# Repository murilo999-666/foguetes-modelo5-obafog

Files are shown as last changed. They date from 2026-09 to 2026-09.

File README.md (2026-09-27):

# Dois foguetes com o motor sólido da OBAFOG

**Página do projeto: https://murilo999-666.github.io/foguetes-modelo5-obafog/**
(gráficos, vistas do OpenRocket, modelos 3D que giram, estimativas e o plano até a Jornada)

Um foguete de alcance para o Modelo 5 da OBAFOG (100ª Jornada de Foguetes, Turma 15,
dezembro de 2026) e um foguete livre com computador de voo e paraquedas. Os dois usam o motor
sólido oficial da OBAFOG e são impressos em 3D.

| | Foguete 1 — OBAFOG Modelo 5 | Foguete 2 — livre |
|---|---|---|
| Objetivo | maior alcance horizontal | voo vertical com eletrônica e paraquedas |
| Simulado com o motor nominal (7 N·s) | 384 m de alcance, a 44° | 114 m de apogeu, descida a 4,5 m/s |
| Arquivo principal | `foguete1_obafog/F1_construtivel_v1.ork` | `foguete2_livre/F2_29mm_v1.ork` |
| Resumo | [foguete1_obafog/LEIA-ME.md](foguete1_obafog/LEIA-ME.md) | [foguete2_livre/LEIA-ME.md](foguete2_livre/LEIA-ME.md) |

Os números vêm de simulação no OpenRocket 24.12. A OBA não publica o impulso do motor: a faixa
de projeto vai de 5 a 11,5 N·s, e o teste estático (bancada em `motor/teste_estatico/`) é o
próximo passo para trocar a faixa por um número medido.

## Onde está cada coisa

- [LEIA-ME.md](LEIA-ME.md): índice do projeto e como abrir os arquivos
- [regulamento/CONFORMIDADE.md](regulamento/CONFORMIDADE.md): o regulamento regra por regra, com a página citada
- [pesquisa/PESQUISA.md](pesquisa/PESQUISA.md): dossiê de pesquisa com as fontes
- [motor/](motor/): modelo do motor, curvas `.eng` e bancada de teste estático
- [foguete1_obafog/](foguete1_obafog/) e [foguete2_livre/](foguete2_livre/): `.ork`, STL, moldes, montagem, eletrônica e firmware
- [scripts/](scripts/): o código que gerou os números (OpenRocket via Python, CAD, otimização)
- [REVISAO.md](REVISAO.md): revisão crítica do projeto
- [docs/](docs/): o código da página

Os PDFs de terceiros usados na pesquisa não foram republicados aqui; os links para eles estão
em `pesquisa/PESQUISA.md`.

## Segurança

O motor deve ser feito exatamente como nos vídeos oficiais da OBA, com o professor. Este
repositório não traz a receita do propelente e não recomenda nenhuma alteração no motor.

---

Projeto de Murilo ([@murilo999-666](https://github.com/murilo999-666)). Pesquisa, simulações,
CAD e código desenvolvidos com auxílio do Claude, a IA da Anthropic.

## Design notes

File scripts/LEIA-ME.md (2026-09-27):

# Scripts — como refazer tudo

Dois Pythons:
- **venv do orx** (`C:\Users\muril\openrocket-optimizer\.venv\Scripts\python.exe`): tudo que usa
  o OpenRocket 24.12 (JPype). Rodar sempre com `-u -X utf8`.
- **Python do sistema** (`python`): CAD (`trimesh` + `manifold3d`), moldes em PDF, imagens.

| Script | Python | O que faz |
|---|---|---|
| `m5lib.py` | venv | biblioteca: constrói os foguetes do zero no OpenRocket (F1, F2, garrafa PET da OBA), motor por configuração de voo, simula cenários, aplica massas do CAD |
| `teste_convencoes.py` | venv | confere azimute, direção do vento e margem estática (rodar depois de mexer na m5lib) |
| `teste_determinismo.py` | venv | mostra que a turbulência do OpenRocket ignora a semente |
| `calibrar_com_voos_oba.py` | venv | garrafas PET de 500 mL x impulso — checagem da faixa do motor |
| `avaliacao.py` / `otimizar_f1.py` | venv | nota robusta e otimização do Foguete 1 (`explorar N`, `humano`; modo construtível por variável de ambiente `M5_MODO=construtivel M5_CONJ=S2`) |
| `avaliar_bf_reto.py` | venv | versões com bordo de fuga reto (imprimível sem suporte) dos melhores construtíveis |
| `comparar_f1.py` | venv | teórico x construtível x humano no mesmo conjunto de cenários; salva `F1_teorico_v1.ork` |
| `finalizar_f1.py <params.json> <versao>` | venv | CAD → massas reais → lastro para 1,40 cal → tabela de ângulos → sensibilidade → Monte Carlo → `.ork` + gráficos + resumo |
| `avaliacao_f2.py` / `otimizar_f2.py` | venv | nota e otimização do Foguete 2 |
| `finalizar_f2.py <params.json> <versao>` | venv | CAD → `.ork` → tabelas de lastro (limite de 150 m) e de deriva → gráfico |
| `exportar_trajetorias_f2.py` | venv | trajetórias do F2 para o teste SIL do firmware |
| `verificar_orks.py` | venv | abre cada `.ork` do disco e roda de novo todas as simulações salvas |
| `cad_foguetes.py f1\|f2\|gabaritos\|massas` | sistema | STL paramétricos e `massas_cad.json` |
| `gerar_moldes.py <D_paraquedas>` | sistema | molde do paraquedas e transferidor da haste (PDF A4, 1:1) |
| `render_previews.py` | sistema | imagem de cada foguete montado |
| `render_openrocket.py <pasta>` | venv, com `ORX_JVM_OPTS=-Djava.awt.headless=false` | vistas lateral e traseira desenhadas pelo próprio OpenRocket (CG, CP, massas), em PNG |
| `exportar_dados_site.py <pasta da página>` | venv | números e curvas da página → `assets/dados.js` |
| `gerar_modelos_web.py <pasta>` | sistema | STL leves para o visualizador 3D da página + `modelos.json` (massas do STL de impressão) |

A página do projeto fica em `../docs/` (GitHub Pages). Depois de mudar um foguete, atualize com
`exportar_dados_site.py ../docs`, `gerar_modelos_web.py ../docs/modelos` e
`render_openrocket.py ../docs/img`.

Os motores são gerados por `../motor/gerar_motores.py` (Python do sistema, só numpy). A curva
medida na bancada entra por `../motor/teste_estatico/para_eng.py`.

Mudou uma cota fixa (diâmetro do cap, folga da impressora)? Edite `m5lib.py`/`cad_foguetes.py`,
rode `finalizar_f1.py`/`finalizar_f2.py` com o `params` da versão e depois `verificar_orks.py`.

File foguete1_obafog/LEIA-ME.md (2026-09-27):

# Foguete 1 — OBAFOG Modelo 5 (alcance)

Corpo de 26 mm impresso, ogiva longa com lastro de massa epóxi no bico, lata de aletas com
luva do motor e as duas guias, motor oficial da OBAFOG preso pelo tubo (o cap fica livre).
Feito para a 100ª Jornada de Foguetes, Turma 15, e serve para a etapa escolar da 21ª OBAFOG.

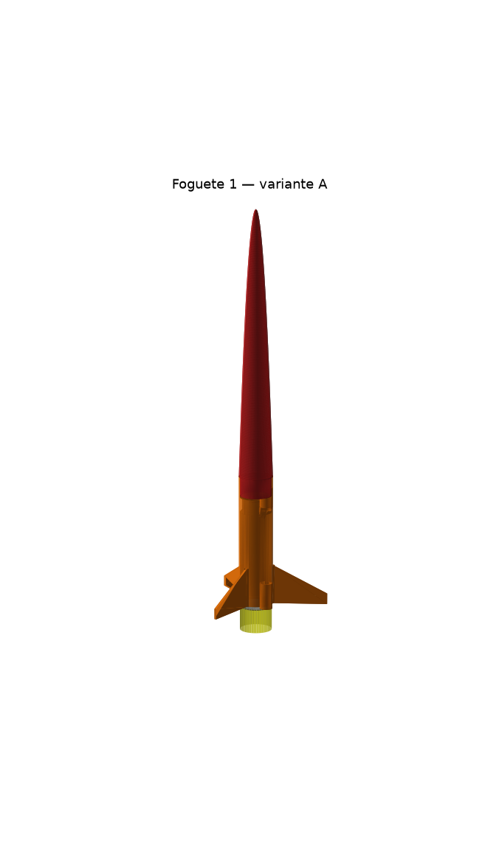
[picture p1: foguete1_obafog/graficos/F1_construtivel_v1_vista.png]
variante A


## Qual imprimir

| | **Variante A** (recomendada) | Variante B (impressora baixa) |
|---|---|---|
| Arquivo | `F1_construtivel_v1.ork` | `F1_construtivel_v1B_ogiva_curta.ork` |
| Peças | **2**: ogiva + lata (as duas guias na lata, alinhadas por construção) | 3: ogiva + tubo + lata (colar com a haste) |
| Ogiva | série de potência (½), 205 mm → **precisa de 220 mm de altura de impressão** | elipsoidal, 150 mm → 165 mm de altura |
| Aletas | 3 x (raiz 30, ponta 8, envergadura 42, bordo de fuga reto), 1,6 mm | 4 x (29, 9, 36), 1,6 mm |
| Lastro de massa epóxi no bico | **12 g** | **9 g** |
| Massa na decolagem (com motor) | **86 g** | 89 g |
| Margem estática com motor / queimado | **1,41 / 2,06 cal** | 1,41 cal |
| Alcance, motor nominal 7 N·s, 44°, sem vento | **384 m** | 363 m |
| 5 / 9 / 11,5 N·s | 248 / 495 / 603 m | 234 / 469 / — |
| Monte Carlo (200 voos com vento, rajada, motor e montagem sorteados) P10 / mediana / P90 | **249 / 386 / 508 m** | 234 / 365 / 484 m |

Massas das peças (do CAD): variante A → ogiva 11,7 g, lata 18,7 g. Tudo em
`F1_construtivel_v1_resumo.json`.

**Expectativa honesta:** o OpenRocket deu mais alcance que o real quando testado nas garrafas
da OBA; conte com algo 10–30% abaixo dos números acima até o primeiro voo de teste.
Garrafas típicas da OBA fazem 100–180 m com o mesmo motor.

## Ângulo da haste (variante A; média dos motores de 5, 7 e 9 N·s)

| Vento na direção do lançamento | Ângulo | Alcance médio |
|---|---|---|
| calmo | **44°** | 376 m |
| 2 m/s de frente | 48° | 363 m |
| 4 m/s de frente | 48° | 350 m |
| 6 m/s de frente | 52° | 337 m |
| 2 m/s de cauda | 44° | 388 m |
| 4 m/s de cauda | 40° | 400 m |
| 6 m/s de cauda | 40° | 412 m |
| 4 m/s lateral | 44° | 364 m |

A curva é **plana**: entre 40° e 48° sem vento o alcance muda menos de 6 m, então a flexão da
haste de 6 mm (~2,5°) quase não pesa. Mesmo assim, meça na metade de cima da haste.
Vento de cauda forte com o motor mais fraco é o pior caso (o foguete empina): prefira esperar
a rajada passar.

## Por que essa forma (resumo da otimização)

- ~2.800 projetos simulados, cada um com 9 a 32 combinações de motor (5–11,5 N·s, 3 formatos
  de curva) e vento (de frente, de cauda, lateral), com margem ≥ 1,2–1,35 cal, saída da vara
  ≥ 11 m/s, flutter com fator ≥ 1,5 e aleta imprimível sem suporte.
- **Mais leve voa mais longe** (correlação −0,88); a ogiva longa dá o braço de alavanca para a
  estabilidade com menos área molhada e menos massa que um tubo, e deixa o lastro bem na frente.
- Comparação no mesmo conjunto de cenários (arquivo `comparacao_S2.json`):

| Projeto | Média | Pior caso | Nominal |
|---|---|---|---|
| Ótimo teórico (aleta 18 x 1,2 mm, frágil) — `F1_teorico_v1.ork` | 381 m | 224 m | 392 m |
| **Construtível (A)** | **362 m** | **205 m** | **370 m** |
| Projeto "humano" (física e intuição, sem otimizar) | 279 m | 151 m | 284 m |

  A aleta robusta custa ~20 m de média; o otimizado ganha ~80 m do projeto feito à mão.
- **Tolerância de fabricação** (`F1_construtivel_v1_resumo.json`, `sensibilidade`): nenhuma
  cota ±1–2 mm muda o alcance em mais de 8 m nem a margem em mais de 0,07 cal. O que mais pesa
  é a massa das peças impressas (±8% → ±8 m) e a do cap (±1,5 g → ±0,06 cal). Pese tudo.

## Arquivos

| | |
|---|---|
| `F1_construtivel_v1.ork` / `..._v1B_ogiva_curta.ork` | abra no OpenRocket 24.12; 9 simulações prontas |
| `F1_teorico_v1.ork` | ótimo teórico, só para referência (não construir) |
| `stl/<versão>/` | STL na orientação de impressão + `gabaritos/` + `massas_cad.json` |
| `moldes/transferidor_haste.pdf` | transferidor que lê a elevação da haste com fio de prumo |
| `MONTAGEM.md` | gabaritos, impressão, colagem, lastro, conferência de CG, motor |
| `CHECKLIST_JORNADA.md` | EPI, raia, vento, ângulo, pós-voo |
| `graficos/<versão>/` | trajetórias, alcance x ângulo, Monte Carlo |
| `otimizacao/` | todas as avaliações (JSONL) |

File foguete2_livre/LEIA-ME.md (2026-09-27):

# Foguete 2 — livre, com eletrônica e paraquedas

Mesmo motor da OBAFOG (o único motor caseiro com projeto testado centenas de vezes), voo
quase vertical (87°), computador de voo que detecta o apogeu pelo barômetro e solta a ogiva;
uma mola empurra o paraquedas para fora. Sem pólvora. Fora de competição.

**Recomendado: `F2_29mm_v1.ork`** (abra no OpenRocket 24.12; os motores OBAFOG já estão
instalados na pasta de curvas do usuário).

## Números (OpenRocket, massas do CAD, campo a ~300 m de altitude, 25 °C)

| | F2_29mm_v1 (recomendado) | F2_26mm_v1 (desempenho) |
|---|---|---|
| Massa na decolagem | 132 g | 122 g |
| Margem estática (com motor) | 1,85 cal | 1,76 cal |
| Comprimento | 385 mm (ogiva elipsoidal 115 + tubo 170 + lata 100) | 345 mm |
| Paraquedas (octógono, PE 35 µm) | 390 mm → desce a 4,45 m/s | 370 mm → 4,48 m/s |
| Apogeu 5 / **7** / 9 / 11,5 N·s | 58 / **114** / 178 / 258 m | 70 / **136** / 208 / 299 m |
| Saída da vara (1,2 m), nominal / pior | 10,1 / 7,9 m/s | 10,6 / 8,4 m/s |
| Deriva com vento de 0 / 2 / 4 / 6 m/s | 17 / 30 / 53 / 92 m | — |
| Lastro para ficar < 140 m com 9 N·s | **21 g** no bico | não cabe (máx. 16 g) |
| Com 11,5 N·s | nem com 63 g: NOTAM ou campo liberado | idem |

O impulso real do motor decide a altura. **Faça o teste estático antes de voar o Foguete 2**
(`../motor/teste_estatico/`) e use a tabela de lastro do resumo.

## Onde está cada coisa

| Arquivo/pasta | O que é |
|---|---|
| `F2_29mm_v1.ork`, `F2_26mm_v1.ork` | projetos com 6 simulações prontas (nominal, 5, 9, 11,5 N·s, curva progressiva, vento lateral) |
| `F2_*_resumo.json` | todos os números, tabela de lastro, tabela de deriva, massas do CAD |
| `stl/F2_29mm_v1/`, `stl/F2_26mm_v1/` | ogiva com baia, tubo (janela + guia), lata de aletas, berço da eletrônica, pistão |
| `moldes/` | molde do paraquedas em tamanho real (A4) |
| `eletronica/` | esquema, lista, firmware (ESP32-C3), teste SIL |
| `MONTAGEM.md` | impressão, montagem, testes no chão, onde lançar |
| `graficos/` | altitude x tempo por motor |
| `otimizacao/` | as 500 avaliações da busca |

## Recomendações que não estão no regulamento de ninguém (é foguete livre)

- **Haste de 1,8–2 m** para o Foguete 2: a saída da vara com 1,2 m é de 8–10 m/s. Com 2 m
  sobe ~30% (a velocidade cresce com a raiz do comprimento).
- Lançar **levemente contra o vento** e **para longe das pessoas**.
- Motor sempre preso com fita crepe **no tubo** e o cap livre, igual ao Foguete 1.

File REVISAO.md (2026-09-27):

# Revisão crítica do projeto (skill engineering-reviewer)

Feita no fim, procurando erro de propósito. Onde achei problema, está dito o que era, a
evidência e o que mudou.

## Escopo

Revisado: regulamento x Foguete 1; modelo do motor; física e restrições da otimização;
estrutura das aletas (flutter); imprimibilidade de todas as peças; transmissão de empuxo e
cap livre; eletrônica e firmware do Foguete 2 (inclusive o teste SIL); segurança e espaço aéreo.
Fora do alcance: o motor físico (curva real), as peças impressas reais (massa e folga), o
vento no dia, a eletrônica montada.

## Bloqueantes — achados e JÁ CORRIGIDOS

| Problema | Evidência | Correção |
|---|---|---|
| **Aleta com bordo de fuga subindo** (ex.: 13 mm ao longo de 44 mm de envergadura): impressa em pé, a borda fica a ~74° da vertical e sai caída sem suporte | geometria das aletas da 1ª variante construível; a regra de impressão da avaliação estava com a desigualdade invertida | **bordo de fuga reto** (enflechamento = raiz − ponta) nos dois foguetes; regra corrigida em `scripts/avaliacao.py`. Bônus: o CP foi para trás, o lastro caiu e a nota subiu de 308 para ~321 |
| Estimativa antiga do motor: 2469 psi numa carcaça de PVC | `_arquivo_estimativa_2026-08-28/` | arquivada; motor novo tratado como caixa-preta com dados dos vídeos oficiais |
| Firmware não detectava o pouso em 210 de 480 casos (ruído zerava o contador) | teste SIL | rejeição de pico no Kalman + velocidade suavizada + tempo máximo de descida → 480/480 |
| Backup por tempo (7 s) abria **antes** do apogeu com o motor de 11,5 N·s (apogeu aos 7,8 s) | teste SIL | backup em 8,5 s |
| Foguete 2 de 26 mm: com motor de 9 N·s passa de 150 m e **não cabe** lastro suficiente | tabela de lastro | recomendado o de 29 mm (21 g resolvem) |
| **STL da lata e do pistão não-manifold** depois que o fatiador funde vértices (~220 e ~140 arestas ruins) | auditoria com `trimesh.load(process=True)`: faces coincidentes (furo subtraído com o mesmo raio dos anéis; disco e saia do pistão dividindo a parede) | subtração redundante removida, pistão em perfil único; **31 de 31 STL estanques, 0 aresta ruim** |
| STL antigo esquecido na pasta da variante A (`F1_tubo_corpo_v1.stl`, de antes do bordo de fuga reto; a versão final não tem tubo) | listagem da pasta | apagado |

## Importantes (não impedem, mas custam alcance ou confiabilidade)

1. **O impulso do motor não é conhecido** (faixa de projeto 5–11,5 N·s). Muda o alcance do
   Foguete 1 de ~200 a ~450 m. Na Jornada o motor é feito no evento, sem chance de medir antes.
   → Teste estático na escola (bancada em `motor/teste_estatico/`) e voos de teste para
   calibrar, como foi feito com o motor de vinagre.
2. **O OpenRocket provavelmente é otimista.** Na calibração com as garrafas da OBA ele deu mais
   alcance que o real. O foguete impresso e pintado é bem mais "limpo" que uma garrafa, mas
   espere algo **10–30% abaixo** da simulação até o primeiro voo real dizer o contrário.
3. **Haste de 6 mm verga e chicoteia.** Flecha estática de ~4 cm e 2,5° na ponta (refeito:
   w = 1,54 N/m, EI = 12,7 N·m², L = 1,3 m); com o foguete passando, mais uns graus. Medir o
   ângulo na metade de cima (transferidor em `foguete1_obafog/moldes/`).
4. **Saída da vara lenta** (12–13 m/s nominal, ~8,5 m/s no pior motor) → sensível a vento.
   Vento de cauda forte com motor fraco pode fazer o foguete empinar e cair perto (0,95 m numa
   simulação com rajada). Usar a tabela de ângulo x vento; se puder, esperar a rajada passar.
5. **Altura de impressão da ogiva da variante A: 220 mm.** Impressora mais baixa → variante B
   (ogiva de 150 mm, 165 mm de altura).
6. **Pouso balístico a ~40 m/s**: a ogiva quebra com frequência. Levar reservas.
7. **Calor do motor no PLA**: lata em **PETG**, fita crepe no tubo, tirar o motor logo.
8. **Cap maior que o corpo** viraria o Dmax do regulamento e aumentaria o arrasto: medir o cap
   (o projeto supõe 24,6 mm < 26 mm).
9. **Foguete 2**: servo precisa aceitar 1S (3,7–4,2 V) — conferir o modelo comprado; saída da
   vara de 8–10 m/s → haste de 1,8–2 m.

## Verifiquei e está OK

- Regulamento: motor intocado, sem metal (lastro de massa epóxi), duas guias, margem 1,4 cal
  (Dmax = corpo de 26 mm), lançamento oblíquo. Tudo com página citada em `regulamento/CONFORMIDADE.md`.
- Margem estática com o motor e **com as massas reais do CAD** (não as do OpenRocket), e a
  mínima em voo ≥ 1,0 cal no cenário nominal.
- **Flutter** refeito à mão para a aleta final (NACA TN 4197): V_flutter ≈ 264 m/s em PLA
  (G = 1,0 GPa) e ≈ 221 m/s em PETG (0,7 GPa), contra ~120 m/s no cenário mais rápido →
  fator ≥ 1,8.
- Empuxo pela borda do tubo de PVC num batente cônico; cap 3 mm atrás da lata, sem contato.
- STL estanques, em milímetros, sem suporte (tetos cônicos, anéis com chanfro, cunha na guia).
- Firmware: compila sem aviso (`--warnings all`), 84% da flash, 30% da RAM; diferença de
  `millis()` em `uint32_t` (sobrevive ao estouro); nenhuma checagem de sensor trava a placa.
- Teste SIL do firmware com as trajetórias finais do OpenRocket: 480/480.
- Espaço aéreo: limite de 150 m (BAR-2/2020) tratado no Foguete 2 com a tabela de lastro.

## Não consegui verificar (falta dado)

- Curva de empuxo real do motor → teste estático.
- Massas e folgas reais das peças impressas → balança e gabaritos.
- Cotas exatas do cap e do cano que a Jornada vai fornecer → paquímetro no evento.
- Arrasto real da superfície impressa e pintada → primeiro voo.
- Dimensões dos módulos eletrônicos que você comprar → medir antes de imprimir o berço.

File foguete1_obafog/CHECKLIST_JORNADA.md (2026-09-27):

# Checklist — Foguete 1 na 100ª Jornada de Foguetes (Turma 15, 07–10/12/2026)

Imprima e leve. O que está em **negrito** custa metros ou desclassifica se esquecer.

## Antes de viajar (na escola)

- [ ] **Voou na escola** com o mesmo projeto (o evento proíbe teste fora da programação).
- [ ] Gabaritos impressos: sei qual furo de luva e qual guia servem na minha impressora.
- [ ] **3 a 4 foguetes prontos**, pintados de laranja/rosa fluorescente, com número e nome
      da escola escritos por dentro da ogiva.
- [ ] Cada foguete pesado **sem motor** e com a margem conferida (ver `MONTAGEM.md`).
- [ ] 2 ogivas extras (quebram no pouso), massa epóxi para lastro e balança de 0,1 g.
- [ ] Transferidor da haste (`moldes/transferidor_haste.pdf`) colado em papelão, fio e porca.
- [ ] Fita crepe (prender o motor), estilete, lixa, cola instantânea, fita adesiva.
- [ ] Anemômetro barato ou app de vento + fitinha amarrada numa vareta (direção do vento).
- [ ] Tabela de ângulo x vento impressa (abaixo).

## EPI (−10 m por item faltando, por aluno) — edital p.16

- [ ] **Calça jeans** e **tênis** (sem bermuda, sem chinelo, nem nas palestras)
- [ ] **Jaleco ou capa de chuva**
- [ ] **Luvas**
- [ ] Protetor facial: a organização empresta; é obrigatório na raia (p.13)
- [ ] Crachá sempre no pescoço

## Na raia, antes do lançamento

1. [ ] O fiscal de acesso confere equipe, EPI, foguete e base; recebe o cartão da raia.
2. [ ] **Direção**: lance **perpendicular à linha de lançamento** (a medida é a distância
       perpendicular; vento lateral não soma nada).
3. [ ] **Vento**: meça a velocidade e veja se é de frente, de cauda ou de lado.
       Escolha o ângulo pela tabela. **Vento de cauda acima de ~5 m/s: pior caso do projeto**
       (o foguete pode empinar e cair perto) — se der para esperar a rajada passar, espere.
4. [ ] Finque a haste de 6 mm firme (15–20 cm no chão). Meça o ângulo **na metade de cima**
       da haste com o transferidor (ela verga ~2° na ponta).
5. [ ] Motor: confira que o cap está **encaixado e sem cola**, com o furo desobstruído.
       Passe **1 volta de fita crepe no tubo de PVC** (nunca no cap) até o motor entrar
       justo na lata. Empurre até o tubo encostar no batente.
6. [ ] Confira que o **cap tem folga** atrás da lata (não pode encostar em nada).
7. [ ] Foguete na haste pelas duas guias; ele tem de **deslizar solto** até embaixo.
8. [ ] Squib lá no fundo do motor (como no vídeo 216), dobrado para não cair, fios separados.
9. [ ] Todos fora da raia; fio de ignição esticado; contagem regressiva em voz alta.
10. [ ] **Olhe o foguete até ele parar** e marque o ponto (árvore, poste, estaca).
       Foguete não achado até 30 min depois do horário de medição = zero.

## Depois

- [ ] Recolha **todo o lixo** da raia (−5 m por item): fita, squib, restos de fio.
- [ ] Tire o motor usado assim que achar o foguete (o PVC quente amolece o PLA).
- [ ] Anote: ângulo, vento, alcance medido, estado do foguete. Esses dados calibram o
      modelo (motor real x simulado) para o 2º dia.

## Tabela de ângulo x vento (variante A; vento medido NA DIREÇÃO do lançamento)

| Vento | Ângulo da haste | Alcance médio simulado* |
|---|---|---|
| calmo (< 1 m/s) | **44°** | 376 m |
| 2 m/s de frente | 48° | 363 m |
| 4 m/s de frente | 48° | 350 m |
| 6 m/s de frente | 52° | 337 m |
| 2 m/s de cauda | 44° | 388 m |
| 4 m/s de cauda | 40° | 400 m |
| 6 m/s de cauda | 40° (evite se puder esperar) | 412 m |
| lateral | 44° | 364 m |

\* média dos motores de 5, 7 e 9 N·s; o real deve ficar 10–30% abaixo até calibrar.
A curva é plana: errar 3–4° custa poucos metros. Variante B: mesmos ângulos (ótimo calmo 44°).

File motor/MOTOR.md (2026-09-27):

# O motor oficial da OBAFOG (Modelo 5)

Os dois foguetes usam **o mesmo motor**: o motor de propelente sólido descrito pela
OBAFOG, que a equipe da OBA diz ter acionado mais de 1.200 vezes sem explosão (live 208,
1:56). Para a OBAFOG ele é obrigatório e **não pode ser alterado em nada**. Para o
foguete livre, ele é a escolha certa pelo mesmo motivo: é o único motor caseiro com
projeto testado centenas de vezes. Aumentar o motor, trocar o cano ou colar o cap é
exatamente o que a OBA avisa que pode explodir (regulamento, p.3).

**Como fabricar o motor: siga os vídeos oficiais 210 a 216, com o professor.** Este
documento não repete a receita. Ele trata o motor como uma **caixa-preta** que precisa
entrar no foguete e no OpenRocket.

## O que se sabe (dado firme)

| Dado | Valor | Fonte |
|---|---|---|
| Carcaça | cano PVC marrom soldável 20 mm, 100 mm de comprimento | regulamento 2026 p.11; vídeo 210 |
| Tubeira | cap soldável 20 mm, furo central de 7 mm (broca 9/32") | vídeo 210, 0:11–3:33 |
| Cap | **não é colado**: salta se a pressão subir (válvula de alívio) | vídeo 210, 17:14–18:55; live 208 |
| Propelente | 22 g, compactado, com furo central | regulamento p.11 |
| Furo central | feito com parafuso de 5/16" (7,9 mm), 85 mm de parte lisa | vídeos 210 e 216 |
| Fechamento dianteiro | bolinha de papel-alumínio compactada + cola + bicarbonato | vídeo 216, 30:00–34:15 |
| Tempo de queima | **~1,2 s** (1,2 a 1,25 s) | live 208, 1:29:35 (muitos testes em balança) |
| Repetibilidade | "todos os motores tinham a curva … muito parecida" | live 208, 1:28:00 |
| Ignição | squib (fósforo elétrico) enfiado até o fundo do furo, 9 V, fio ≥ 20–25 m | vídeos 215/216 |
| Foguetes que já voaram com ele | de menos de 50 g até 200 g | live 208, 1:55 |
| Desempenho mostrado | garrafas de 500 mL: ~100 m repetidos; às vezes > 150 m | live 208, 1:53; vídeo 215, 16:55 |

## O que NÃO se sabe (e como foi tratado)

**A curva de empuxo não é publicada.** Ela aparece rapidamente na live, mas sem números.
Então o impulso foi limitado por medições publicadas de motores parecidos:

| Referência | O que mediu | Isp |
|---|---|---|
| RBEF, "Minifoguete a propelente sólido…" (KNSu 65/35 a frio, KNO3 impuro, 33 g, eletroduto 3/4", bocal de argila) | v_e = 380 m/s derivada do voo (apogeu 72,8 m, 226 g) | ~39 s |
| Marchi / GFCS-UFPR 2021 (KNSu a frio **prensado a 3–10 t**, tubeira metálica, 5–20 bar) | 330 testes | 63–82 s |
| Motor da OBA (compactado por queda de peso, tubeira = furo em plástico que erode) | não publicado | **abaixo dos dois** |

E foi feita uma checagem com os voos que a OBA mostra (`scripts/calibrar_com_voos_oba.py`):
garrafas de 500 mL estáveis no OpenRocket dão 114–162 m com 7 N·s e 158–211 m com 9 N·s,
contra ~100 m reais. Como o OpenRocket costuma **subestimar** o arrasto de foguete
artesanal (fita, coifa rombuda, aleta torta), a conclusão honesta é:

> **impulso nominal = 7 N·s (Isp 32 s); faixa de projeto 5 a 11,5 N·s.**
> Pela classificação da norma BAR-2/2020 é um motor **classe C** (5,01–10 N·s), que
> pode cair na B ou chegar na D. Em código NAR, algo como **C6-P** (P = sem carga de ejeção).

A forma da curva também não é conhecida, então há três envelopes:

| Envelope | Formato | Pico (7 N·s) | O que muda no voo |
|---|---|---|---|
| **REG** | pico no início, depois cai | 11,5 N | sai da vara mais rápido |
| **NEU** | patamar | 7,0 N | caso central |
| **PRO** | começa fraco, cresce | 8,9 N (no fim) | **pior saída da vara** |

Arquivos em `eng/`: `OBAFOG-M5_<envelope>_<impulso>.eng`, com impulsos I05, I07, I09 e I115
(5; 7; 9; 11,5 N·s), mais `NEU_I07_tb10` e `NEU_I07_tb14` (queima de 1,0 e 1,4 s). Todos têm
22 g de propelente e 35,9 g **sem o cap**. O cap (~5 g) entra no foguete como um componente
de massa atrás da lata, porque o CG real do motor fica atrás do centro geométrico e isso
muda a margem em ~0,1 cal.

`gerar_motores.py` gera a família inteira (não precisa de OpenRocket).

## Massas e cotas a conferir na balança e no paquímetro

| Item | Valor usado | Por que importa |
|---|---|---|
| Diâmetro externo do cano | 20,0 mm | folga da luva (gabaritos de 20,3 a 20,9 mm) |
| Diâmetro externo do cap | 24,6 mm | tem de ser **menor que o corpo** (26 mm), senão vira o Dmax |
| Comprimento do cap | 18 mm | define o balanço do motor atrás da lata |
| Massa do cap | 5 g | CG do motor |
| Massa do motor carregado (sem cap) | 35,9 g | massa de decolagem e CG |
| Massa do motor queimado | ~14 g + resíduo | CG depois da queima |

## Como medir de verdade: teste de resistência e teste estático

A norma BAR-2/2020 manda esta ordem, e ela faz sentido:

1. **Teste de resistência** — o motor queima preso numa base, **sem instrumento**. Serve
   para ver se ele funciona sem anomalia, medir o tempo de queima filmando (celular a
   60 fps dá ±0,02 s) e pesar o resíduo. Faça com o professor, no mesmo protocolo de
   segurança do lançamento (fio de 25 m, protetor facial, ninguém perto).
2. **Teste estático** — o motor empurra uma célula de carga. Mede a curva de empuxo.
   Pasta `teste_estatico/`:
   - `bancada_estatica.ino` — Arduino Uno/Nano + HX711 + célula de carga de 5 kg;
   - `para_eng.py` — transforma as medições num `.eng` do OpenRocket (média de vários motores).
3. **Teste de voo** — só com motor aprovado nos dois anteriores.

Com 3 a 5 testes estáticos, a faixa de 5 a 11,5 N·s vira um número com ±10%, e a
simulação do alcance fica tão boa quanto a do motor de vinagre depois da calibração.

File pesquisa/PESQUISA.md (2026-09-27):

# Dossiê de pesquisa — dois foguetes com o motor sólido da OBAFOG

Tudo o que fundamenta as decisões de projeto, com a fonte de cada número. Onde não há
fonte, está escrito "estimado" e diz como medir.

## 1. O alvo: Modelo 5 e a 100ª Jornada de Foguetes

- **Modelo 5** = "tubular com propulsão sólida", ensino médio ou superior, lançamento
  **oblíquo**, vence o **maior alcance horizontal** (Regulamento 20ª OBAFOG Modelo 5, p.2–3).
- Formato e material livres, **menos metal**; impressão 3D citada explicitamente (p.2 e p.10).
- **Motor obrigatório** e intocável: o descrito nos vídeos 208 e 210–216 (p.3, p.10).
- Vara de 1,2–1,5 m que não verga; o foguete leva **duas guias** que passam pela vara (p.11).
- Estabilidade (CP−CG)/Dmax "igual ou ligeiramente maior do que 1,0" (p.9–10).
- A etapa escolar mede do ponto de lançamento até onde o foguete parou, em metros inteiros
  arredondados para cima (p.3). O prazo de 2026 era 15/05/2026 (p.5).
- **100ª Jornada de Foguetes, Turma 15** (07–10/12/2026, Barra do Piraí/RJ) é a única turma
  de 2026 com Modelo 5. As equipes **não levam motor**: ele é fabricado no evento com material
  da organização (oficina de motores/teste estático no 2º dia). A organização empresta uma
  **haste de aço de 6 mm x 1,5 m**, fincada no ângulo que a equipe escolher (edital p.15).
- Na Jornada, o alcance é a distância **perpendicular à linha de lançamento** (edital p.13).
  São 2 lançamentos, um por dia, e vale o maior. Foguete não achado até 30 min depois da
  medição fica com zero (p.13–14). Recomendam levar 2 foguetes novos (p.15).
- Análise completa rotulada (PERMITIDO/PROIBIDO/AMBÍGUO): `../regulamento/CONFORMIDADE.md`.

## 2. O motor oficial

Resumo em `../motor/MOTOR.md`. Dados firmes, tirados das legendas automáticas dos vídeos
oficiais (baixadas com `yt-dlp`):

| Dado | Valor | Onde |
|---|---|---|
| Carcaça | PVC marrom soldável 20 mm, 100 mm | regulamento p.11; vídeo 210 |
| Tubeira | cap 20 mm, furo de 7 mm, **não colado** (salta como alívio de pressão) | vídeo 210, 0:11–3:33 e 17:14–18:55 |
| Furo central | molde = parafuso de 5/16" (7,9 mm), 85 mm lisos | vídeos 210 e 216 |
| Propelente | 22 g, compactado em 2 porções de 11 g | regulamento; vídeo 216, 22:30 |
| Fechamento dianteiro | papel-alumínio compactado + cola instantânea + bicarbonato | vídeo 216, 30:00–34:15 |
| **Tempo de queima** | **~1,2 s** (1,2–1,25 s), curvas "muito parecidas" em muitos testes | live 208, 1:28–1:29 |
| Histórico | >1.200 acionamentos sem explosão | live 208, 1:56 |
| Foguetes já usados | de <50 g a 200 g | live 208, 1:55 |
| Desempenho mostrado | garrafas de 500 mL: ~100 m repetidos; >150 m em alguns voos | live 208, 1:53; vídeo 215, 16:55 |
| Fixação no foguete | fita crepe ou esparadrapo | vídeo 215, 7:31; live 208, 1:31 |
| Vara usada pela OBA | vergalhão liso 4–6 mm, 1,5 m, ~15 cm enterrado | vídeo 215, 3:28 |

**Impulso (não publicado)** — limitado por dois trabalhos:

- *Minifoguete a propelente sólido: aspectos teóricos e propostas experimentais para o
  ensino de física* (Revista Brasileira de Ensino de Física, SciELO). KNSu 65/35 **a frio**,
  KNO3 impuro, 33 g, eletroduto 3/4", 108 mm, furo de 5,6 x 89 mm, bocal de argila. Queima de
  0,70 s, foguete de 226 g, apogeu de 72,8 m, v_max 55 m/s → **v_e ≈ 380 m/s (Isp ≈ 39 s)**.
- Marchi, C. H. (GFCS/UFPR), *Propelente KNSu a frio para minifoguetes: preparo,
  carregamento, estocagem e uso* (2021). KNSu a frio **prensado a 3–10 t**, tubeiras metálicas,
  5–20 bar, 330 testes: **Isp real de 63–82 s**. Massa específica do KNSu prensado:
  1.314–1.556 kg/m³ (70–82% da teórica). O próprio texto diz: "O motor-foguete da MOBFOG/OBA
  usa KNSu a frio."
- Foltran et al. (SAB 2014, UFPR): a velocidade de queima **à pressão atmosférica** cai com
  a compactação, e densidade × velocidade de queima ≈ constante. Isso é coerente com 1,2 s de
  queima numa parede de ~4,5 mm (pressão de câmara baixa, poucos bar).
- **Checagem com os voos da OBA** (`../scripts/calibrar_com_voos_oba.py`): garrafas de 500 mL
  estáveis (1,0–1,6 cal, 130–150 g) dão no OpenRocket 114–162 m com 7 N·s e 158–211 m com
  9 N·s, contra ~100 m reais. O OpenRocket subestima o arrasto de foguete artesanal.
- **Conclusão: nominal 7 N·s (Isp 32 s), faixa 5–11,5 N·s** — motor classe C pela norma
  BAR-2/2020 (5,01–10 N·s). A forma da curva é desconhecida: três envelopes (regressivo,
  neutro, progressivo).

## 3. Física do alcance com um motor fraco

Resultados das simulações (OpenRocket 24.12, 2.800 projetos avaliados, cada um em 9 a 30
cenários de motor e vento):

1. **Área frontal manda.** Uma garrafa de 65 mm tem ~6 vezes a área frontal de um tubo de
   26 mm. Com o mesmo motor, a garrafa típica fica em 100–180 m e o foguete fino passa de 300 m.
2. **Mais leve voa mais longe** (correlação alcance x massa = −0,88 com a margem mínima
   imposta). É a mesma lição do bit07: o lastro só entra na medida exata para a estabilidade.
3. **O motor de 41 g fica na cauda**, então o foguete precisa de CP bem atrás (aletas) ou de
   CG à frente (ogiva longa e ~10 g de lastro). A busca prefere **ogiva longa + corpo curto +
   lastro pequeno**, em vez de corpo comprido.
4. **Ângulo ótimo ~45–50°** sem vento (foguete sai devagar da vara e faz curva de gravidade;
   por isso passa um pouco de 45°). Com vento, o ótimo muda: ver a tabela do guia de lançamento.
5. **Saída da vara lenta (~10–13 m/s)** é o ponto fraco: com vento, o foguete "cata-vento"
   forte. Vento de cauda de 6 m/s com o motor mais fraco pode deixar o foguete quase vertical
   e fazê-lo cair perto da base (0,95 m numa das simulações com rajada). **Não lançar com
   vento de cauda forte.**
6. **A haste de 6 mm verga.** Aço de 6 mm, 1,3 m livres, a 45°: flecha na ponta ≈
   wL⁴/(8EI) ≈ 4 cm e inclinação ≈ 2,5° a menos na ponta (w = 1,54 N/m, E = 200 GPa,
   I = 63,6 mm⁴). Meça o ângulo na metade de cima da haste, ou some ~2° na base.
7. **O OpenRocket ignora a turbulência na semente** (o resultado muda a cada rodada). A
   comparação de projetos foi feita sem turbulência; a dispersão por rajada foi medida à parte
   (Monte Carlo).

## 4. Estabilidade

- Margem estática = (CP − CG)/D, com D = maior diâmetro do corpo (norma BAR-2/2020 e
  regulamento). O cap do motor (~24,6 mm) é menor que o corpo de 26 mm, então não vira o Dmax.
- CP calculado pelo `BarrowmanCalculator` do próprio OpenRocket (não à mão: no bit07 a
  conta manual errou 0,72 cal).
- Faixa de projeto: **1,35 a 2,0 cal**, com margem para o erro de massa e CG da impressão
  (a sensibilidade está no resumo de cada foguete).

## 5. Estrutura

- **Flutter** (NACA TN 4197, forma divulgada pela Apogee), com G de peça impressa
  conservador (PLA 1,0 GPa; PETG 0,7 GPa), pressão de 380 m de altitude: todas as aletas
  aprovadas têm V_flutter ≥ 1,5 x a maior velocidade simulada (motor de 11,5 N·s regressivo).
- **O OpenRocket não vê fragilidade.** Sem restrição, a busca leva a aleta para 18 mm de raiz
  e 1,2 mm de espessura. Por isso existe a **variante construível** (raiz ≥ 28 mm, espessura
  ≥ 1,6 mm, envergadura ≤ 45 mm).
- **Pouso balístico a ~40 m/s**: a ogiva quebra com frequência. Imprima ogivas de reserva
  (~7 g, ~1 h cada).
- **Calor**: queima de 1,2 s, mas o cano de PVC esquenta depois. PLA amolece a partir de
  ~60 °C, PETG ~80 °C. A lata tem **vão de ar** entre o cano e a casca (só os anéis encostam),
  e a fita crepe no cano isola. Tire o motor logo depois de achar o foguete.
- **Cap livre**: o empuxo passa pela borda do tubo de PVC, que encosta num batente cônico.
  O cap fica 3 mm atrás da lata e nada encosta nele.

## 6. Impressão 3D

- Peças impressas **em pé** (eixo do foguete na vertical): a flexão da aleta fica no plano da
  camada, a guia sai redonda, sem suporte (tetos cônicos e cunhas de 45°).
- Paredes de 0,8 mm (2 perímetros de 0,4 mm), aletas de 1,6–2,0 mm.
- Massas calculadas do próprio STL (volume x densidade: PLA 1,24 g/cm³, PETG 1,27 g/cm³) e
  **devolvidas ao OpenRocket** como massa e CG de cada componente.
- **Gabaritos antes do foguete**: anéis de 20,3–20,9 mm para o cano e guias de 6,8–8,0 mm para
  a haste. O FDM fecha furo ~0,1–0,2 mm, e cada impressora é diferente.

## 7. Foguete 2: recuperação e eletrônica

- **Sem pólvora**: servo + mola. Detalhes, números de datasheet (ESP32-C3 23–28 mA; BMP280
  ±0,12 hPa relativo) e o teste SIL (480/480 aprovados) em
  `../foguete2_livre/eletronica/ELETRONICA.md`.
- **Paraquedas** de polietileno (saco de lixo grosso, ~35 µm), Cd ≈ 0,8, dimensionado para
  ~4,5 m/s de descida: D = √(8·m·g / (π·ρ·Cd·v²)).
- **Altura e espaço aéreo**: a norma BAR-2/2020 (Associação Brasileira de Minifoguetes)
  orienta pedir **NOTAM** ao CINDACTA se o apogeu estimado passar de **150 m em área rural**
  (300 m em área urbana). O Foguete 2 faz 130 m com 7 N·s, mas 200 m com 9 N·s. Por isso há a
  tabela de lastro para limitar o apogeu depois do teste estático.

## 8. Segurança

- Vídeo obrigatório da OBA: "Segurança em primeiro lugar" (https://youtu.be/Bp6O71fHFIg).
- Protocolo da OBA (vídeo 215): zonas verde/amarela/vermelha; público a pelo menos metade do
  apogeu esperado; fio de ignição de 20–25 m; máscara/protetor facial; supervisão de adulto.
- Sequência de testes da BAR-2/2020: **teste de resistência** (queima presa, sem instrumento)
  → **teste estático** (com célula de carga) → **voo**. Motor só voa se passou nos dois.
- **Não alterar o motor** (maior, outro cano, cap colado). O GFCS/UFPR, com prensa, tubeiras
  metálicas e anos de prática, relata "vários acidentes, sem vítimas, durante a queima de
  KNSu em motores-foguete nas fases de testes em solo". Motor maior é projeto para fazer com
  um grupo experiente (o próprio GFCS/UFPR, do Festival Baranoff).

## Fontes

- OBA/OBAFOG — Regulamento da 20ª OBAFOG, Modelo 5 (17/02/2026):
  http://www.oba.org.br/sisglob/sisglob_arquivos/2026/REGULAMENTO%20DA%2020%C2%AA%20OBAFOG%20PARA%20O%20MODELO%205%20-%202026-compactado.pdf
- OBA/OBAFOG — Regulamento da 20ª OBAFOG, Modelo 7 (placa eletrônica exclusiva da OBA):
  https://sistema.oba.org.br/sisglob/sisglob_arquivos/2026/REGULAMENTO%20DA%2020%C2%AA%20OBAFOG%20PARA%20O%20MODELO%207%20-%202026-compactado.pdf
- Edital da 100ª Jornada de Foguetes, Turma 15 (08/06/2026) — arquivo local `EDITAL-TURMA-15.pdf`.
- Vídeos oficiais da OBA: 208 https://youtu.be/K09RnU6daIM · 210 https://youtu.be/HOY6TW5Y5a4 ·
  212 https://youtu.be/Dfe2eF72smU · 214 https://youtu.be/KAxPLGZrsJU ·
  215 https://youtu.be/xJjJKmWx2xI · 216 https://youtu.be/QO-kHBZBfBs ·
  Segurança https://youtu.be/Bp6O71fHFIg · OpenRocket https://youtu.be/CfT25FJbSuo
- Minifoguete a propelente sólido: aspectos teóricos e propostas experimentais para o ensino
  de física — Revista Brasileira de Ensino de Física: https://scielo.br/j/rbef/a/dTQnxcQT6TGhnkYmMx4H6Sx/?lang=pt
- Marchi, C. H. — Propelente KNSu a frio para minifoguetes (GFCS/UFPR, 2021):
  http://ftp.demec.ufpr.br/foguete/Divulgacao/2021_Propelente_KNSu_a_frio_para%20minifoguetes_preparo_carregamento_estocagem_e_uso_Marchi.pdf
- Foltran, A. C. et al. — Medição da velocidade de queima à pressão atmosférica do propelente
  KNSu (SAB 2014): http://ftp.demec.ufpr.br/foguete/Trabalhos/2014_Foltran_Moro_Silva_Ferreira_Araki_Marchi_SAB_2014.pdf
- Associação Brasileira de Minifoguetes — Norma BAR-2/2020 (nomenclatura; NOTAM; testes):
  http://ftp.demec.ufpr.br/foguete/apostila/norma-BAR-2-2020_versao_2020-12-03.pdf
- Marchi, C. H. — Capítulo 3, Estabilidade (apostila citada pelo regulamento):
  http://ftp.demec.ufpr.br/foguete/apostila/Capitulo_03_Estabilidade.pdf
- Espressif — ESP32-C3 Series Datasheet (consumo em modem-sleep): https://www.espressif.com/sites/default/files/documentation/esp32-c3_datasheet_en.pdf
- Bosch Sensortec — BMP280 Datasheet rev 1.26: https://www.bosch-sensortec.com/media/boschsensortec/downloads/datasheets/bst-bmp280-ds001.pdf
- NACA TN 4197 (flutter de painel), na forma da Apogee Components (Peak of Flight #291/#411).
- Niskanen, S. — Development of an Open Source model rocket simulation software (OpenRocket,
  documentação técnica: Barrowman estendido, modelos de arrasto).

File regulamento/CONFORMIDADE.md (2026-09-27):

# Conformidade — Foguete 1 x regulamento do Modelo 5

```
MODALIDADE:   OBAFOG Modelo 5 — "tubular com propulsão sólida", nível 4 (ensino médio)
REGULAMENTO:  "Regulamento da 20ª OBAFOG para o Modelo 5 – 2026" (Rio de Janeiro, 17/02/2026, 11 p.)
              + Edital da 100ª Jornada de Foguetes, Turma 15 (08/06/2026, 23 p.)
EVENTO ALVO:  100ª Jornada de Foguetes — Turma 15 — 07 a 10/12/2026, Hotel Fazenda Ribeirão,
              Barra do Piraí/RJ. É a ÚNICA turma de 2026 que lança Modelo 5 (edital p.15).
PRAZO:        inscrição (boleto pago + ficha Excel) até 13h de 20/10/2026 — quem pede é o professor.
```

Rótulos usados (skill `robotics-competition`): **PERMITIDO** (o texto autoriza),
**PROIBIDO** (o texto veda), **AMBÍGUO** (texto omisso ou com duas leituras),
**PRECISA CONFIRMAR** (só a organização resolve).

## 1. Motor

| Item | Rótulo | Onde está | Como o projeto trata |
|---|---|---|---|
| Só o motor descrito pela OBAFOG | **PROIBIDO alterar** | Reg. p.3 ("Em hipótese alguma é permitido alterar qualquer item do motor… sob pena da escola ser desclassificada em todos os seus níveis"), p.10 | O foguete foi projetado **em volta** do motor oficial. Nada no motor muda. |
| Motor feito na Jornada com material da organização | regra do evento | Edital p.15 ("As equipes devem trazer os seus foguetes, MAS NÃO OS SEUS MOTORES") | A luva aceita qualquer motor feito conforme os vídeos 210–216. |
| Prender o motor no foguete com fita crepe/esparadrapo | **PERMITIDO** | É o método mostrado pela própria OBA (vídeo 215, 7:31; live 208, 1:31) | Encaixe por atrito com 1 volta de fita crepe **no tubo de PVC**, nunca no cap. |
| Cap (tubeira) não colado, livre para saltar | exigência de segurança do motor | Vídeo 210, 17:14–18:55; live 208, 0:37 e 1:57 | O cap fica **fora** do foguete, 3 mm atrás da lata. O empuxo passa pela borda dianteira do tubo, que encosta num batente. **Não encostar nada no cap, não passar fita no cap.** |

## 2. Construção do foguete

| Item | Rótulo | Onde está | Situação do projeto |
|---|---|---|---|
| Formato livre | **PERMITIDO** | Reg. p.2, item 10 | ok |
| Tubo impresso em impressora 3D | **PERMITIDO** | Reg. p.2 ("d) com tubo impresso em impressora 3D") e p.10 ("e) Foguete impresso em impressora 3D") | PLA ou PETG |
| Qualquer material que não seja metal | **PERMITIDO**; metal **PROIBIDO** | Reg. p.2 ("g) com qualquer material que não seja metálico") e p.10 | Plástico impresso, fita, tinta. **Lastro de massa epóxi (Durepoxi), nunca porca, chumbo ou prego.** Nenhum parafuso. |
| Duas "guias" que passam pela vara, sem aperto | **PERMITIDO/EXIGIDO** | Reg. p.11 ("O foguete deve carregar duas 'guias' que passam por dentro da vara e não podem ser muito apertadas") | 2 guias impressas, furo de 7,65 mm para a haste de 6 mm (gabaritos testam 6,8–8,0 mm). |
| Estabilidade (CP−CG)/Dmax "igual ou ligeiramente maior do que 1,0" | **AMBÍGUO** | Reg. p.9–10 | O projeto usa **1,3 a 1,6 cal** com Dmax = diâmetro do corpo (26 mm). O cap tem ~24,6 mm, **menor** que o corpo, então não vira o Dmax. "Ligeiramente maior" não tem número; ficamos abaixo de 2 cal, que é o limite usual de "sobre-estável". Não há, nos documentos, verificação de CP no evento. |
| Eletrônica a bordo (ex.: bip para achar o foguete) | **AMBÍGUO** | Reg. não menciona para o Modelo 5; placa tem metal | **Não usamos.** Para achar o foguete: tinta fluorescente e o professor seguindo a trajetória (edital p.13). |
| Paraquedas | fora do objetivo | Modelo 5 mede "onde parou o foguete" (reg. p.3) | Não usamos: paraquedas encurtaria o alcance. |

## 3. Lançamento

| Item | Rótulo | Onde está | Situação |
|---|---|---|---|
| Só lançamento oblíquo, objetivo maior alcance | **PERMITIDO/EXIGIDO** | Reg. p.3, item 12 | Projeto otimizado para alcance. |
| Ângulo "próximo de 45 graus" (etapa escolar) | **AMBÍGUO** | Reg. p.11 ("inclinação próxima de 45 graus") | O ótimo sai entre ~45 e 50 graus. |
| Ângulo à escolha da equipe (Jornada) | **PERMITIDO** | Edital p.15 ("fincada no chão no ângulo em que a equipe escolher") | Tabela de ângulo x vento no guia de lançamento. |
| Vara de 1,2 a 1,5 m, lisa, que não encurve | **PERMITIDO** | Reg. p.11 | A Jornada empresta haste de aço de **6 mm x 1,5 m** (edital p.15). Ela verga uns 4 cm na ponta com o próprio peso a 45 graus: medir o ângulo na metade de cima, ou somar ~2 graus na base. |
| Base própria | **PERMITIDO** | Edital p.15 ("As equipes podem trazer as suas bases e sistemas de ignição") | Opcional. |
| Base tem de ficar presa ao chão | **EXIGIDO** (−10 m se soltar) | Edital p.16 | Vale para base própria; a haste da Jornada é fincada. |
| Ignição elétrica, 9 V, fio de 25 m | regra do evento | Reg. p.5; edital p.15 (a organização fornece) | Não afeta o foguete. |

## 4. Medição e prova

| Item | Rótulo | Onde está | Consequência para o projeto |
|---|---|---|---|
| Etapa escolar: distância do ponto de lançamento até onde o foguete parou, metro inteiro arredondado para cima | regra | Reg. p.3, item 13 | Métrica "total". |
| Jornada: distância **perpendicular** à linha de lançamento | regra | Edital p.13 ("não se mede distância entre o ponto de lançamento e ponto de parada") | Métrica "perp", a usada na otimização. **Lançar perpendicular à linha.** Vento lateral não soma nada. |
| Foguete não achado até 30 min depois do horário de medição = zero | regra | Edital p.13–14 | Tinta laranja/rosa fluorescente; alguém da equipe acompanha a queda. |
| 2 lançamentos (1 por dia), vale o maior | regra | Edital p.15 | Levar **pelo menos 3 foguetes** prontos (ogiva quebra no pouso balístico). |
| Explosão do foguete = alcance zero | regra | Edital p.15 | Depende de montar o motor exatamente como nos vídeos. |
| Proibido testar foguete fora da programação | **PROIBIDO** | Edital p.9 | Testar na escola antes. |
| EPI: calça jeans, tênis, jaleco ou capa, luvas; protetor facial | **EXIGIDO** (−10 m por item por aluno) | Edital p.13, p.16 | Checklist. |
| Lixo deixado na raia | **PROIBIDO** (−5 m por item) | Edital p.17 | Recolher fita, fio, squib. |

## 5. Pendências para a organização

Mandar pelo professor para **coord.obfog@gmail.com** (o edital diz que é o único
canal para assuntos da Jornada; seg–sex, 7h–15h). E-mail separado do pedido de boleto.

> Assunto: Dúvidas técnicas — Modelo 5 — 100ª Jornada, Turma 15
>
> Prezada coordenação, somos da escola ______ (código OBA ____), inscrita para a
> Turma 15. Temos quatro dúvidas sobre o foguete do Modelo 5:
>
> 1. O corpo do foguete será impresso em PLA/PETG e o lastro será de massa epóxi
>    (sem nenhuma peça metálica). Isso atende a "qualquer material que não seja metálico"?
> 2. A estabilidade do nosso foguete é (CP−CG)/Dmax ≈ 1,5. O regulamento pede "igual
>    ou ligeiramente maior do que 1,0". Existe algum limite superior ou alguma
>    verificação no evento?
> 3. O motor é entregue à equipe para ela mesma encaixá-lo e prendê-lo com fita crepe
>    no foguete, como nos vídeos? E o motor feito na Jornada é o mesmo dos vídeos
>    (cano PVC marrom 20 mm x 100 mm, cap com furo de 7 mm)? Nosso encaixe foi
>    dimensionado para ele.
> 4. Se levarmos base própria, podemos usar uma haste lisa de 6 mm com 1,5 m, e
>    escolher o ângulo livremente, como diz o edital?
>
> Obrigado.

## 6. PRECISA CONFIRMAR (com o professor, antes de tudo)

- **A escola recebeu mesmo o convite para a Turma 15?** O edital convida escolas que
  **lançaram Modelo 5** na 20ª OBAFOG (prazo 15/05/2026). Se a escola não lançou Modelo 5
  até essa data, o alvo passa a ser a 21ª OBAFOG (etapa escolar de 2027) e a Jornada de
  2027. O foguete serve para os dois casos; muda só a métrica (perpendicular x total) e o
  ângulo ("próximo de 45 graus" na etapa escolar).

## Risco de reprovação

**Baixo.** O foguete não mexe no motor, não tem metal, tem as duas guias e margem acima
de 1,0. O único ponto aberto é o "ligeiramente maior do que 1,0" (item 2), que não tem
número nem inspeção prevista. O risco real no dia não é de regra, é de operação: vento
forte de cauda com motor fraco (ver o guia de lançamento) e foguete perdido no mato.

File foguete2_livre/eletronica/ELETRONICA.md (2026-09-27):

# Eletrônica do Foguete 2 — computador de voo com paraquedas por servo

Objetivo: detectar o apogeu pelo barômetro e soltar a ogiva (o paraquedas sai empurrado
por uma mola), registrar o voo e ajudar a achar o foguete no chão. **Sem pólvora**: a
carga de ejeção comum usa pólvora negra, produto controlado, e o motor da OBAFOG não tem
carga de ejeção. Servo + mola é recarregável, testável na bancada quantas vezes quiser.

## O que é obrigatório e o que é opcional

| Item | Status | Por quê (número) |
|---|---|---|
| ESP32-C3 SuperMini | **obrigatório** | ~2 g, 22,5 x 18 mm; 23–28 mA com Wi-Fi desligado a 160 MHz (datasheet Espressif, modo modem-sleep, CPU rodando) |
| BMP280 (ou BMP390) | **obrigatório** | é quem vê o apogeu; precisão relativa ±0,12 hPa = ±1 m (datasheet Bosch rev 1.26) |
| Micro servo ~3,7 g | **obrigatório** | trava a ogiva; aceita 1S (3,7–4,2 V) — **conferir no anúncio**, varia por modelo |
| LiPo 1S 150–250 mAh | **obrigatório** | ver autonomia abaixo |
| Chave liga/desliga | **obrigatório** | desligar a bateria antes de plugar o USB (ver alerta) |
| Buzzer ativo 3–5 V + NPN (S8050/BC337) + 1 kΩ | **obrigatório na prática** | sem ele, achar o foguete no mato é sorte; o buzzer puxa ~20–30 mA, mais do que um GPIO deve fornecer — por isso o transistor |
| Divisor 100k/100k para ler a bateria | recomendado | mostra "CARREGAR" na página; custa 2 resistores |
| MPU6050 | **opcional** | melhora o instante da decolagem (acelerômetro vê em ~20 ms; o barômetro só em ~0,4 s). O teste SIL passou 100% **só com barômetro** |
| Diodo Schottky SS14/1N5817 bateria→5V | opcional | só necessário se você quiser plugar o USB com a bateria ligada |
| Capacitor 220–470 µF perto do servo | opcional | só se o servo resetar a placa ao mexer (na bancada dá para ver) |

## Ligação

```
                 chave
 LiPo+ ──────────o/ o────┬──────────────► pino 5V da SuperMini (regulador da placa -> 3V3)
                         ├──────────────► servo VCC (vermelho)
                         ├──[100k]──┬──[100k]── GND
                         │          └──────► GPIO3 (leitura da bateria)
                         └──► buzzer (+) ── buzzer (−) ──► coletor NPN
 LiPo− ─────────────────────── GND comum (placa, servo marrom/preto, sensores, emissor do NPN)

 GPIO4 ──[1k]──► base do NPN          GPIO5 ──► servo sinal (laranja/amarelo)
 GPIO6 ──► SDA  (BMP280, MPU6050)      GPIO7 ──► SCL (BMP280, MPU6050)
 3V3   ──► VCC dos sensores            GPIO8 = LED azul da placa (acende em LOW)
```

Por que esses pinos: no ESP32-C3 os pinos de boot são o **2, o 8 e o 9** (na SuperMini o 8
tem o LED e o 9 o botão BOOT); 18/19 são o USB. O ADC da bateria fica no ADC1 (GPIO3),
que funciona com o Wi-Fi ligado.

**ALERTA:** a bateria entra no pino 5V. Se o USB for plugado com a chave ligada, o USB
empurra 5 V na LiPo. Regra: **chave desligada para plugar o USB** (ou coloque o diodo).

## Orçamento de corrente e autonomia

| Consumidor | Corrente | Fonte |
|---|---|---|
| ESP32-C3, Wi-Fi desligado | 23–28 mA (+~10 mA acessando flash) | datasheet ESP32-C3 |
| ESP32-C3 com AP Wi-Fi (só no chão) | ~80–120 mA médio, picos de 300 mA | datasheet (TX/RX) |
| BMP280 a ~50 Hz | < 1 mA | datasheet |
| MPU6050 (opcional) | ~3,9 mA | datasheet InvenSense |
| Servo segurando | ~5–10 mA; movendo ~100–250 mA | **medir** (genérico) |
| Buzzer bipando | ~25 mA x fração do tempo | anúncio |
| LED da placa | ~2–5 mA | estimado |

Armado (Wi-Fi desligado): ~45 mA. Com 250 mAh e 80% útil: **250 x 0,8 / 45 ≈ 4,4 h** na
rampa. Com o AP ligado (preparo): ~1,5 h. Carregue antes de cada dia de lançamento.

## Massa (entra no OpenRocket como componentes de massa)

| Item | g |
|---|---|
| ESP32-C3 SuperMini | 2,0 |
| BMP280 | 1,0 |
| LiPo 250 mAh | 5,5 |
| micro servo | 3,7 |
| buzzer + NPN + resistores | 1,5 |
| fios e chave | 3,0 |
| berço impresso | 4,0 |
| **total** | **~20,7** |

Pese tudo na balança de cozinha (0,1 g) e corrija `F2_PADRAO` em `scripts/m5lib.py`.

## Firmware (`firmware/computador_voo/`)

- `voo.h` — lógica de voo **portátil** (Kalman de altitude/velocidade + estados). A mesma
  lógica roda no PC no teste SIL.
- `bmp280_min.h` — driver mínimo do BMP280/BME280 (sem biblioteca; aceita os dois chip IDs).
- `computador_voo.ino` — hardware, log, Wi-Fi.

Compila limpo com `--warnings all` (core esp32 3.3.12, placa "ESP32C3 Dev Module",
**USB CDC On Boot: Enabled**): 84% da flash, 30% da RAM (inclui 60 kB de log).

Estados: PREPARO → ARMADO → SUBIDA → DESCIDA → POUSADO.

| Regra | Valor | Por quê |
|---|---|---|
| Decolagem | altitude filtrada > 4 m **e** subindo > 6 m/s (ou acelerômetro > 3 g) | rajada no chão não passa nas duas |
| Bloqueio | 1,6 s depois da decolagem | motor queima ~1,2 s: nunca abre queimando |
| Apogeu | velocidade < −0,3 m/s por 4 amostras, **ou** caiu 2,5 m do máximo | só acima de 12 m |
| Backup | 8,5 s depois da decolagem | apogeu mais tardio simulado: 7,4 s (motor de 11,5 N·s) |
| Pouso | velocidade suavizada < 0,8 m/s por 3 s, ou 120 s depois da abertura | salva o voo, liga Wi-Fi, bipa o apogeu |
| Pico de sensor | resíduo > 6σ é ignorado (até 5 seguidas) | picos de ±60 Pa no teste |
| Reset em voo | se a placa reiniciar em SUBIDA/DESCIDA (queda de tensão), abre na hora | melhor abrir cedo que nunca |

## Teste SIL — o firmware real contra o OpenRocket (`sil/`)

`teste_voo.cpp` compila o `voo.h` no PC (`python -m ziglang c++`), recebe a trajetória do
OpenRocket, converte altitude em pressão, soma ruído de barômetro, rajadas no chão
(60 s armado), picos de ±60 Pa em 1% das amostras e 0,4 s de sensor congelado na
propulsão, e amostra a 50 Hz com jitter, como o `loop()`.

**Resultado: 480 de 480 casos aprovados** (6 motores x 2 ventos x 2 ruídos x picos x
falha x 5 sementes). Trajetórias do F2 de 29 mm, sem vento (com vento de 4 m/s o
apogeu cai 4–8 m e o resultado é o mesmo; tudo em `sil/resultado_sil.jsonl`):

| Trajetória | Apogeu | Abertura depois do apogeu (média / máx) | Velocidade vertical na abertura (máx) |
|---|---|---|---|
| 5 N·s | 58 m | 0,39 / 0,51 s | 4,9 m/s |
| 7 N·s (nominal) | 114 m | 0,39 / 0,55 s | 5,1 m/s |
| 9 N·s | 178 m | 0,41 / 0,59 s | 5,5 m/s |
| 11,5 N·s | 258 m | 0,39 / 0,52 s | 4,8 m/s |

Zero decolagem falsa no chão, pouso detectado em todos. A primeira versão da lógica
reprovou 210 casos (o pouso não era detectado com ruído) e abria 0,3 s **antes** do
apogeu no motor mais forte: foi o SIL que achou, e as correções estão no `voo.h`.

## Testes de bancada antes de voar

1. **Ruído do barômetro**: ligado e parado, a página mostra o ruído medido (esperado
   0,1–0,4 m). Acima de 0,8 m: sensor ruim, luz ou vento no furo.
2. **Trava**: "Destravar"/"Travar" pela página; o braço tem de entrar ~2 mm na janela do
   tubo e sair totalmente. Ajuste `SERVO_TRAVA_US`/`SERVO_SOLTA_US`.
3. **Ejeção no chão**: foguete montado, paraquedas dobrado, "Destravar" → a ogiva tem de
   sair e puxar o paraquedas para fora. Faça 10 vezes. Se enroscar, a mola é fraca ou o
   paraquedas está apertado demais.
4. **Voo de mão**: armado, suba uma escada ou um prédio (5–10 m) e desça: não pode abrir
   (fica abaixo de 12 m e não detecta decolagem) — mostra que não há disparo falso.
5. **Teste de elevador/carro** (opcional): subir 15 m ou mais e descer detecta "apogeu".
6. **Bateria**: > 3,9 V para voar.

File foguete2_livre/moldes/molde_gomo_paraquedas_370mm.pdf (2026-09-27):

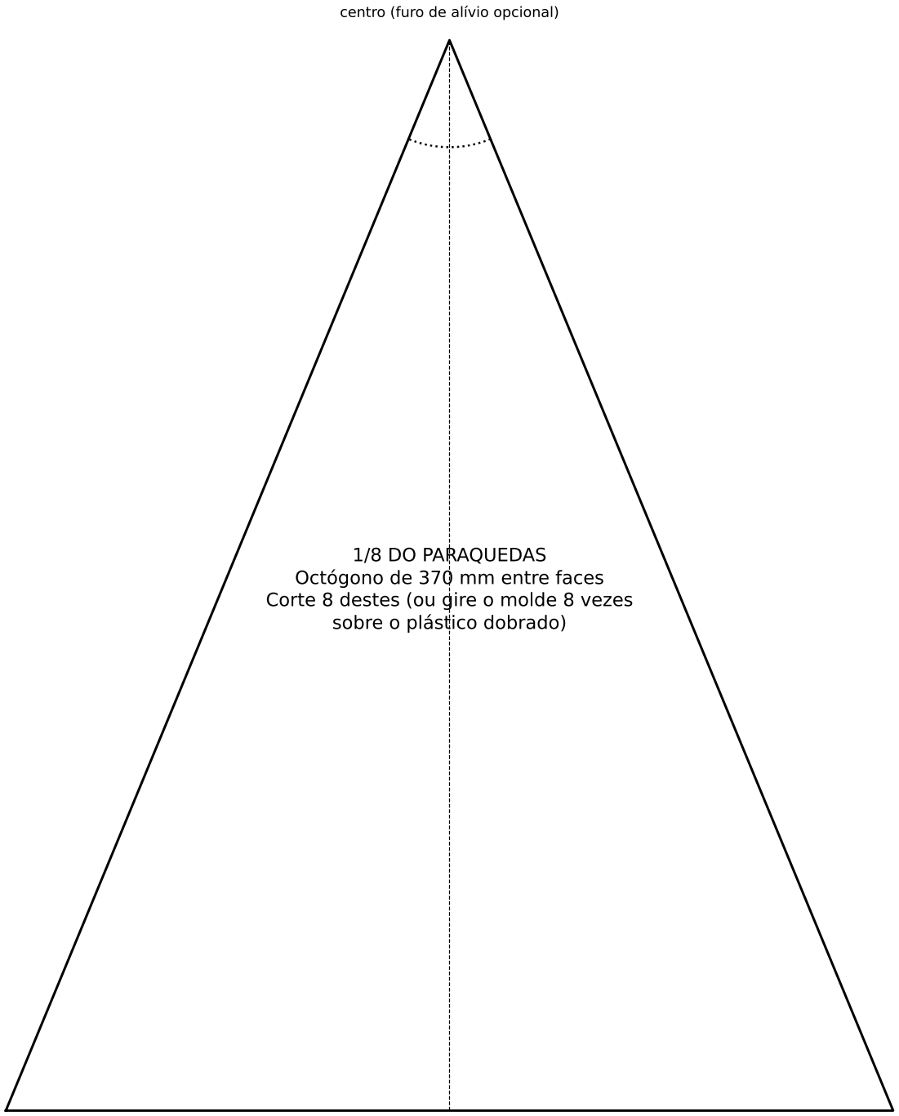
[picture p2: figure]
centro (furo de alívio opcional); 1/8 DO PARAQUEDAS Octógono de 370 mm entre faces Corte 8 destes (ou gire o molde 8 vezes sobre o plástico dobrado)

borda externa: 153 mm — reforce os 2 cantos com fita e amarre uma linha em cada

# Foguete 2 — molde do paraquedas

Material: saco de lixo grosso (~35 µm) ou ripstop. 8 linhas de nylon, cada uma com o comprimento de 370 mm, presas nos 8 cantos com fita (dobre a fita sobre a linha). Junte as 8 pontas num nó e prenda no cordão de choque.

100 mm (confira antes de cortar)

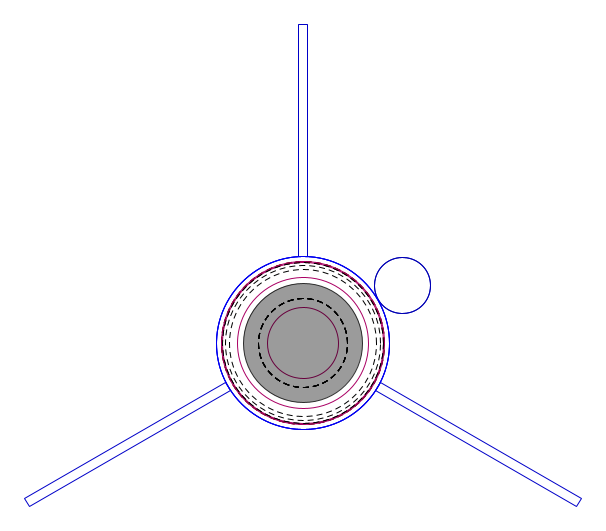
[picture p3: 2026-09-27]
docs/img/openrocket_F2_29_traseira.png

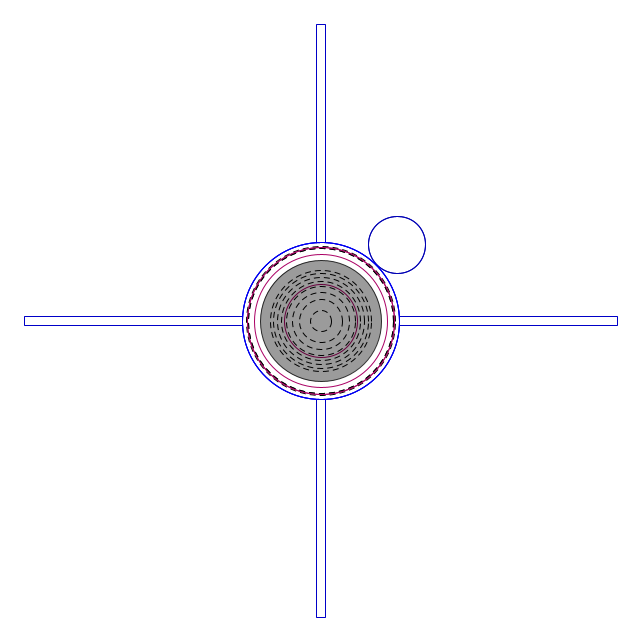
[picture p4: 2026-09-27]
docs/img/openrocket_F1_B_traseira.png

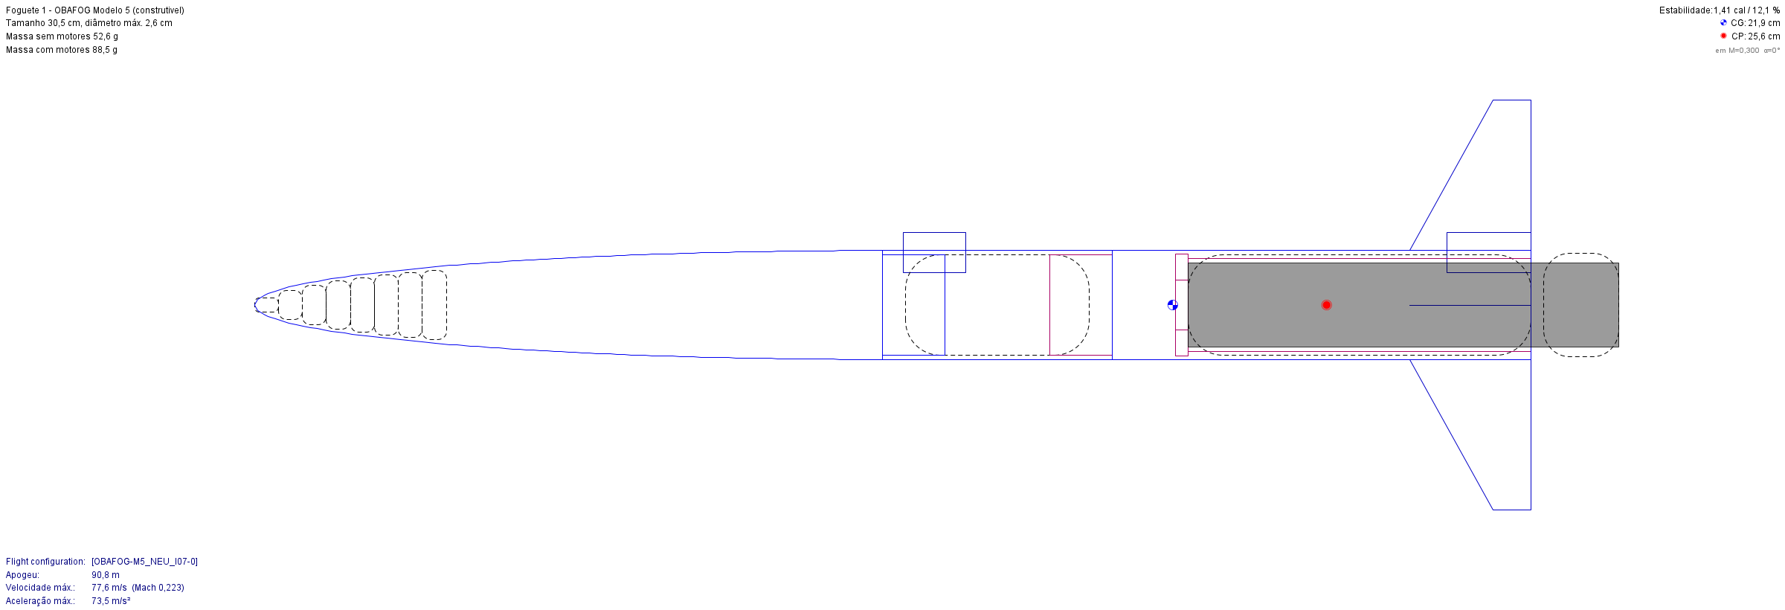
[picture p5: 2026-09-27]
docs/img/openrocket_F1_B_lateral.png

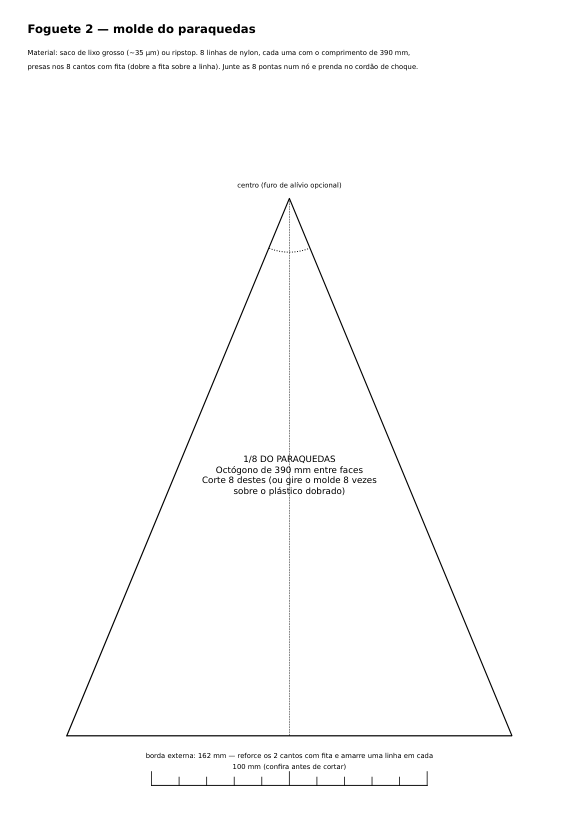
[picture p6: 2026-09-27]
docs/img/molde_paraquedas.png

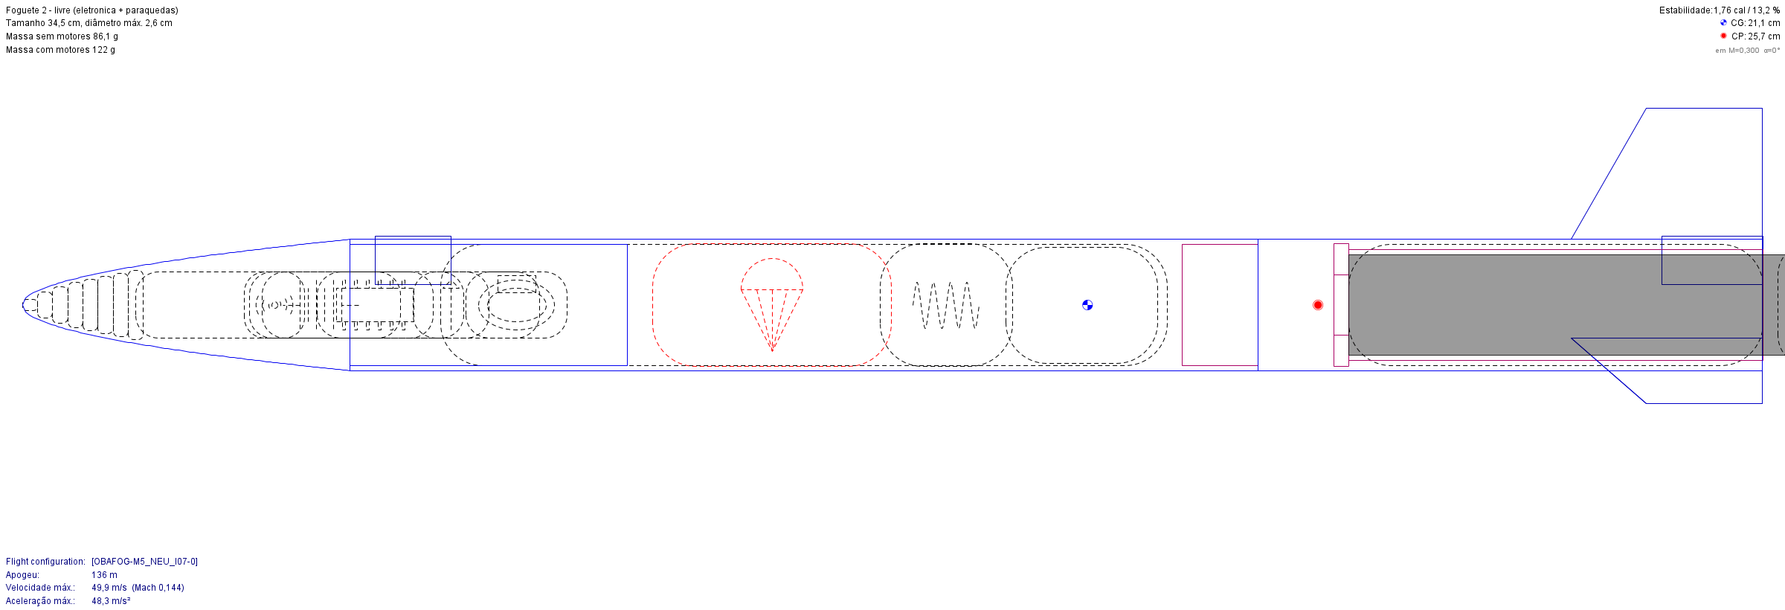
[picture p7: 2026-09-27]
docs/img/openrocket_F2_26_lateral.png

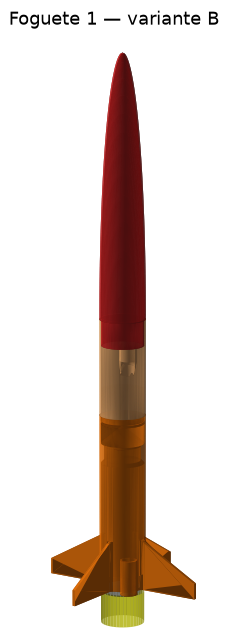
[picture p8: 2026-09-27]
docs/img/render_F1_B.png

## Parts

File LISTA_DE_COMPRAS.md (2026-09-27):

# Lista de compras e custo (estimativa, setembro de 2026)

Preços de referência de loja de ferragens, agropecuária e marketplace. São **estimativas
para planejar**: confira na hora de comprar. O que já tem em casa sai de graça.

## Foguete 1 (OBAFOG) — por foguete

| Item | Quantidade | Custo aprox. |
|---|---|---|
| Filamento PLA (ou PETG) | ~45 g com as perdas (ogiva + lata; + tubo se houver) | R$ 4–6 |
| Massa epóxi (Durepoxi) para o lastro | ~10–15 g (de um tubo de 100 g) | R$ 2–3 |
| Fita crepe (prender o motor) | um rolo serve a temporada toda | (R$ 6–8 o rolo) |
| Tinta spray fluorescente (laranja ou rosa) | uma lata pinta vários foguetes | (R$ 30–40 a lata) |

**Leve 3 a 4 foguetes para a Jornada** (2 lançamentos e a ogiva pode quebrar no pouso).
Quatro foguetes: ~R$ 30 de material + tinta e fita compartilhadas.

## Motor (para os testes na escola — na Jornada a organização fornece)

Siga os vídeos 210–216 com o professor. Materiais citados nos vídeos:

| Item | Observação | Custo aprox. |
|---|---|---|
| Cano PVC marrom soldável 20 mm | 1 barra rende dezenas de motores de 100 mm | R$ 15–25 a barra |
| Cap soldável 20 mm | 1 por motor (sai deformado da queima) | R$ 1–2 cada |
| Fertilizante nitrato de potássio 12-00-45 | agropecuária ou internet, pacotes de 0,5–3 kg | R$ 30–60 o kg |
| Açúcar de confeiteiro (sem amido) | | R$ 6–10 |
| Squib (fósforo elétrico) | loja de fogos ou internet | R$ 2–5 cada |
| Fio paralelo de 25 m + bateria de 9 V | ignição à distância | R$ 30–50 |

As ferramentas (broca de 7 mm, parafusos de 3/8" e 5/16", luva de correr, moedor, balança)
estão no vídeo 210. Muitas escolas já têm.

## Bancada de teste estático (recomendada, serve aos dois foguetes)

| Item | Custo aprox. |
|---|---|
| Célula de carga de barra 5 kg + módulo HX711 | R$ 20–35 |
| Arduino Uno/Nano (pode reaproveitar) | R$ 30–45 |
| Base de madeira, parafusos, abraçadeiras | R$ 10–20 |

## Foguete 2 (livre)

| Item | Status | Custo aprox. |
|---|---|---|
| ESP32-C3 SuperMini | obrigatório | R$ 20–30 |
| Sensor BMP280 (módulo I2C 3,3 V) | obrigatório | R$ 10–15 |
| Micro servo ~3,7 g (compatível com 1S) | obrigatório | R$ 20–35 |
| LiPo 1S 150–250 mAh + carregador TP4056 | obrigatório | R$ 25–40 |
| Chave liga/desliga mini | obrigatório | R$ 2 |
| Buzzer ativo 3–5 V + transistor S8050/BC337 + resistor 1 kΩ | obrigatório na prática | R$ 5 |
| Resistores 100 kΩ (x2) | recomendado | centavos |
| MPU6050 | opcional (você já tem) | — |
| Diodo Schottky SS14/1N5817 | opcional | R$ 1 |
| Mola de compressão (Ø ≤ 20 mm, 30–50 mm de comprimento) | obrigatório | R$ 3–6 |
| Elástico de 3 mm (cordão de choque, 1,2 m) | obrigatório | R$ 5 |
| Saco de lixo grosso + linha de nylon (paraquedas) | obrigatório | R$ 5 |
| Filamento PLA | ~60 g | R$ 6–8 |

**Eletrônica: ~R$ 90–130. Foguete 2 completo: ~R$ 110–150** (sem o motor).

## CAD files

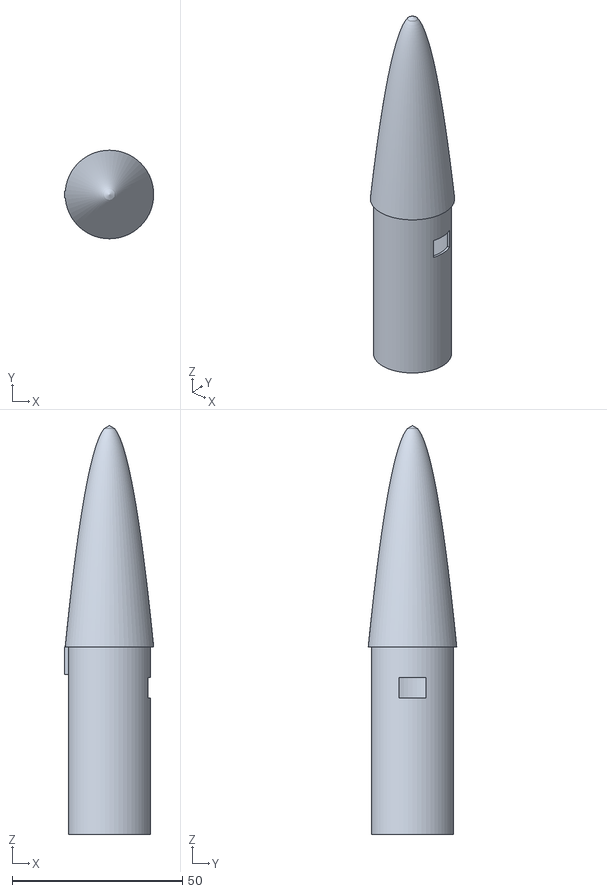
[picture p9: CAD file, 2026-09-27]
docs/modelos/F2_26_ogiva.stl
26.2 x 26.0 x 120.0

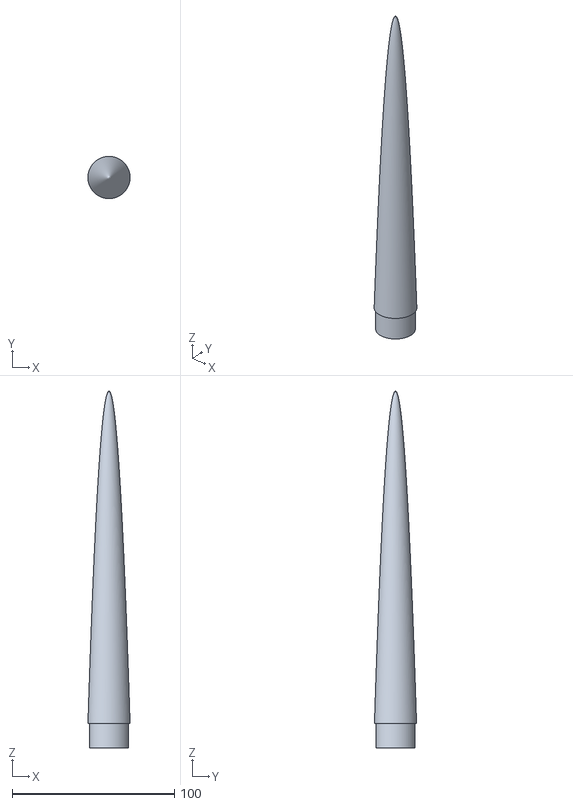
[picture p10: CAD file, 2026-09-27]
foguete1_obafog/stl/F1_construtivel_v1/F1_ogiva_v1.stl
26.0 x 26.0 x 220.0

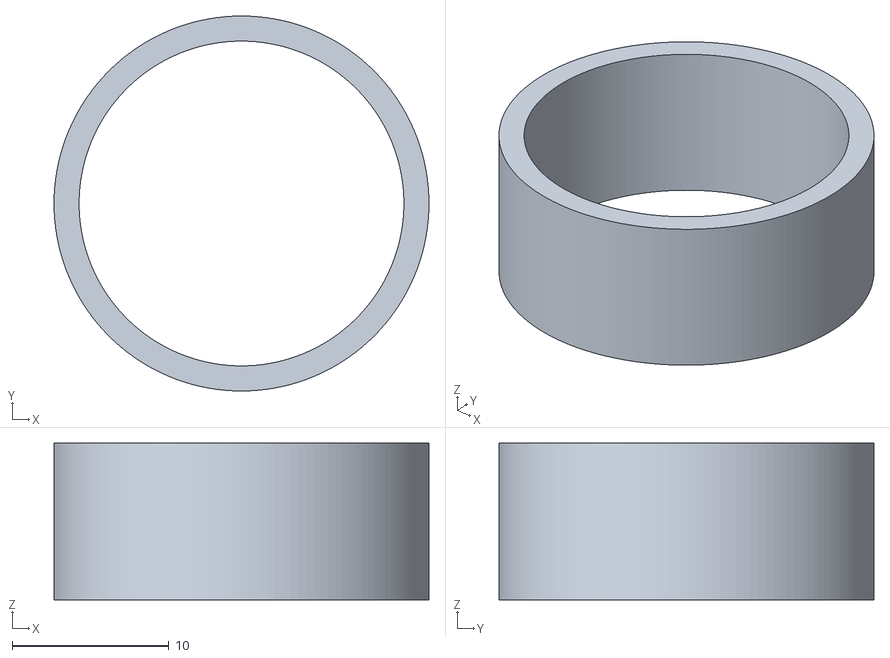
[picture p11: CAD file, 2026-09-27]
foguete1_obafog/stl/F1_construtivel_v1/gabaritos/gab_luva_motor_ID20.7_v1.stl
23.9 x 23.9 x 10.0

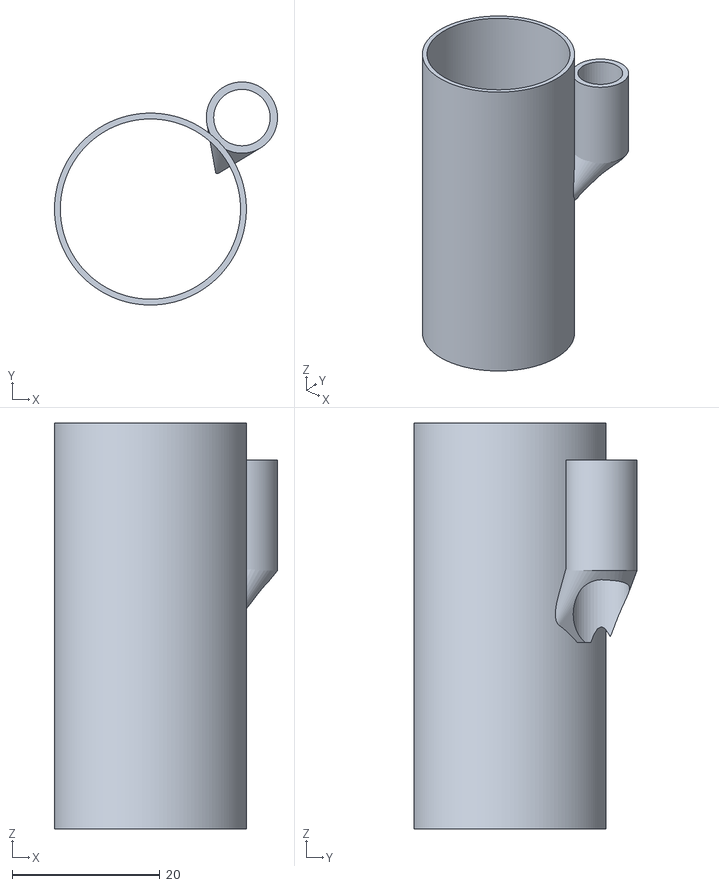
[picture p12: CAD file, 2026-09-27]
foguete1_obafog/stl/F1_construtivel_v1B_ogiva_curta/F1_tubo_corpo_v1.stl
30.2 x 30.2 x 55.0

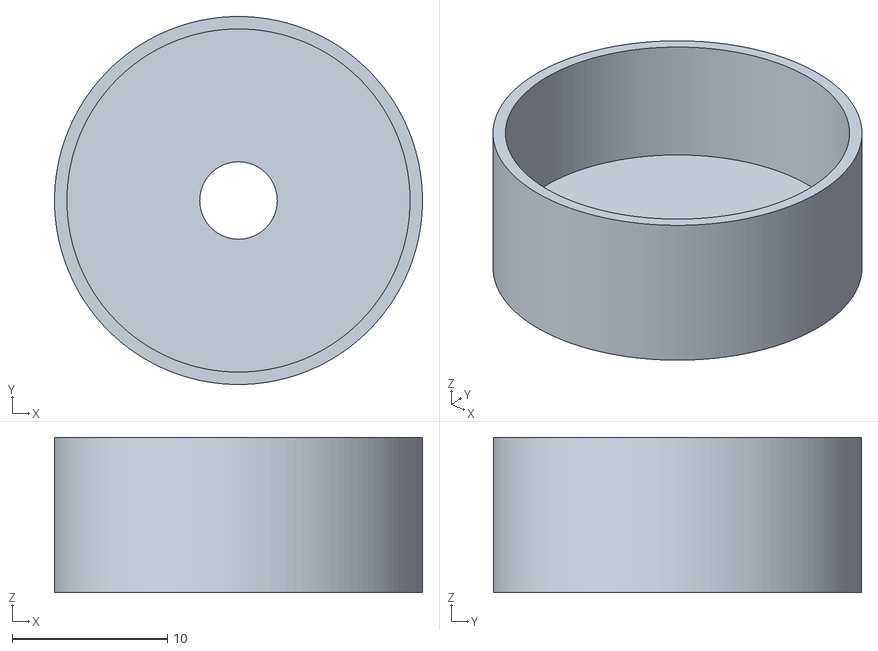
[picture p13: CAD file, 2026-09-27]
foguete2_livre/stl/F2_26mm_v1/F2_pistao_v1.stl
23.7 x 23.7 x 10.0

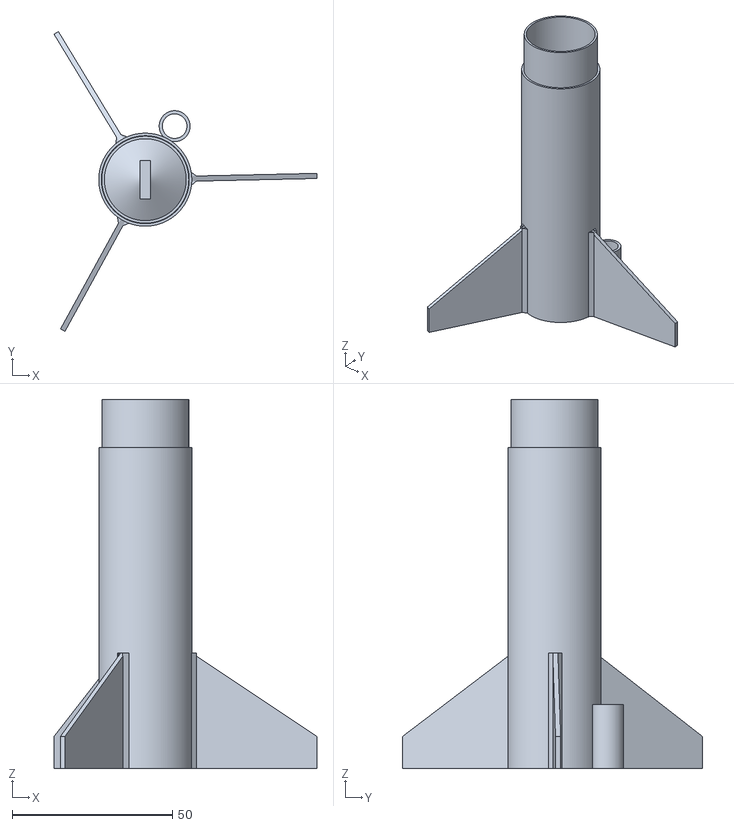
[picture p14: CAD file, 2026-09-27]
foguete2_livre/stl/F2_29mm_v1/F2_lata_aletas_v1.stl
81.9 x 93.4 x 115.0

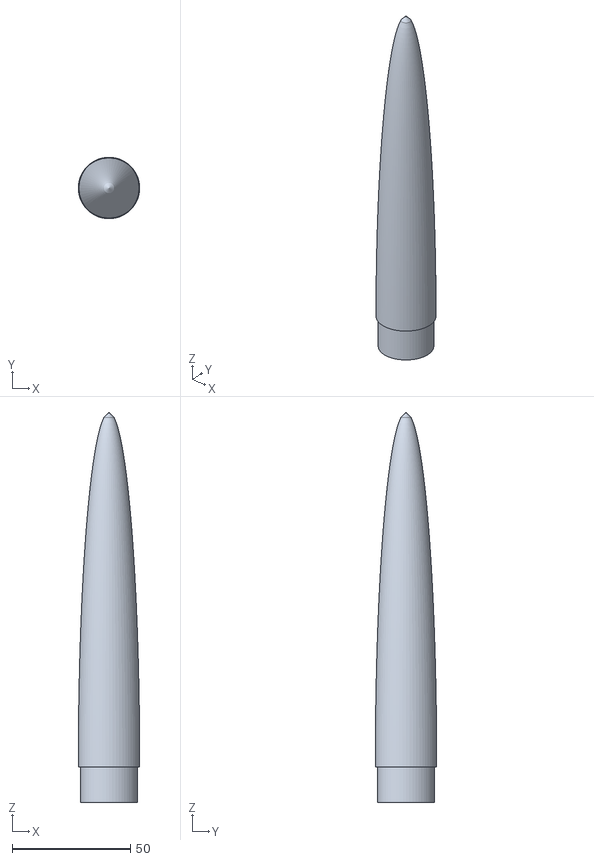
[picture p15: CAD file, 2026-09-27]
docs/modelos/F1_B_ogiva.stl
26.0 x 26.0 x 165.0

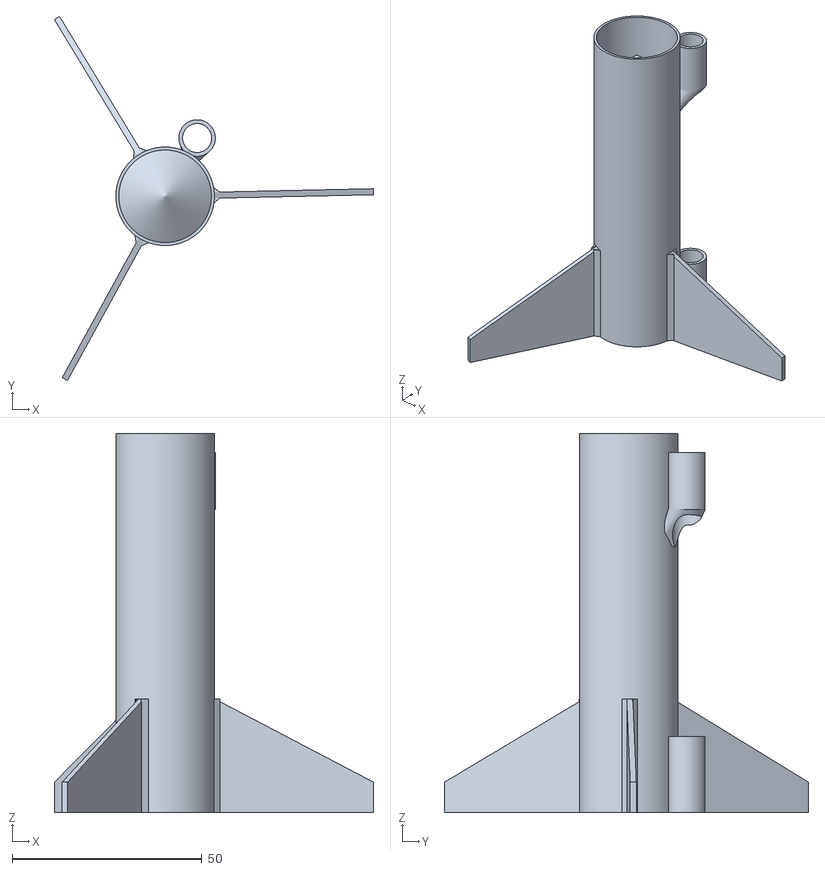
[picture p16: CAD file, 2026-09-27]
foguete1_obafog/stl/F1_construtivel_v1/F1_lata_aletas_v1.stl
84.2 x 96.0 x 100.0

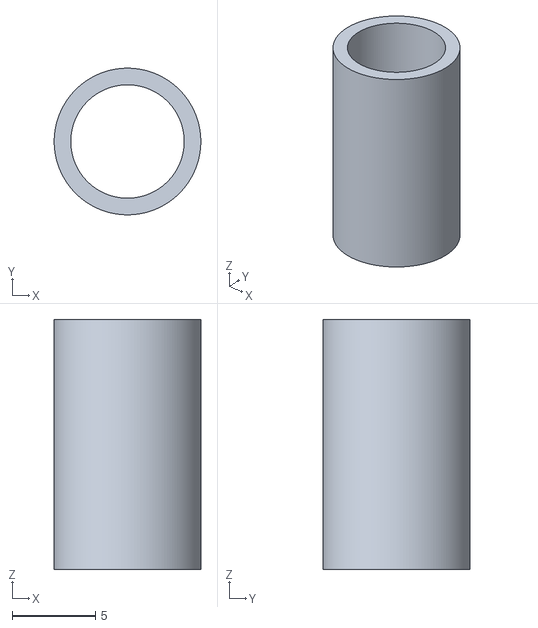
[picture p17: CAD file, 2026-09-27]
foguete1_obafog/stl/F1_construtivel_v1/gabaritos/gab_guia_haste6_ID6.8_v1.stl
8.80 x 8.80 x 15.0

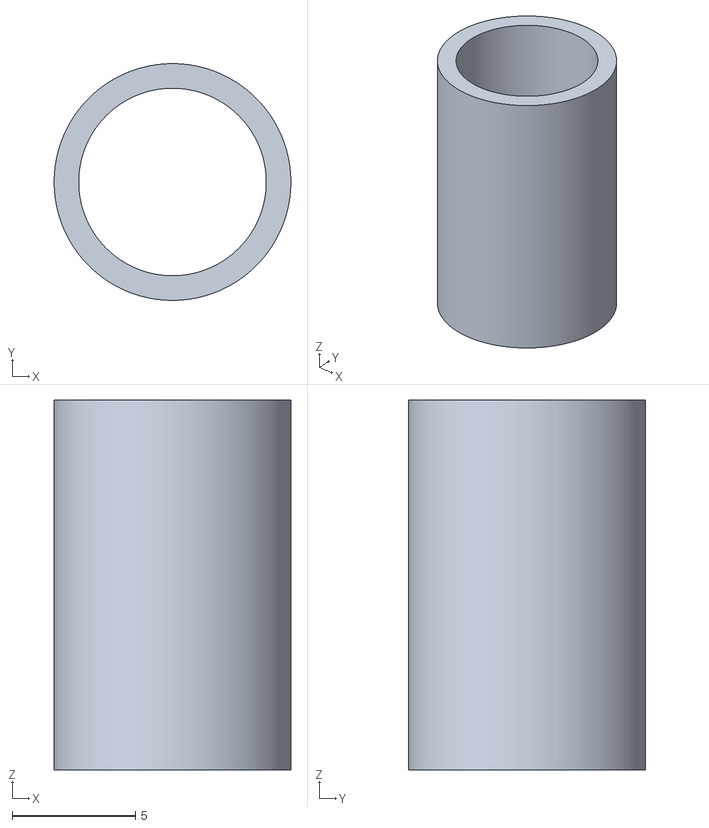
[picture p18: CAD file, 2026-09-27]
foguete1_obafog/stl/F1_construtivel_v1B_ogiva_curta/gabaritos/gab_guia_haste6_ID7.6_v1.stl
9.60 x 9.60 x 15.0

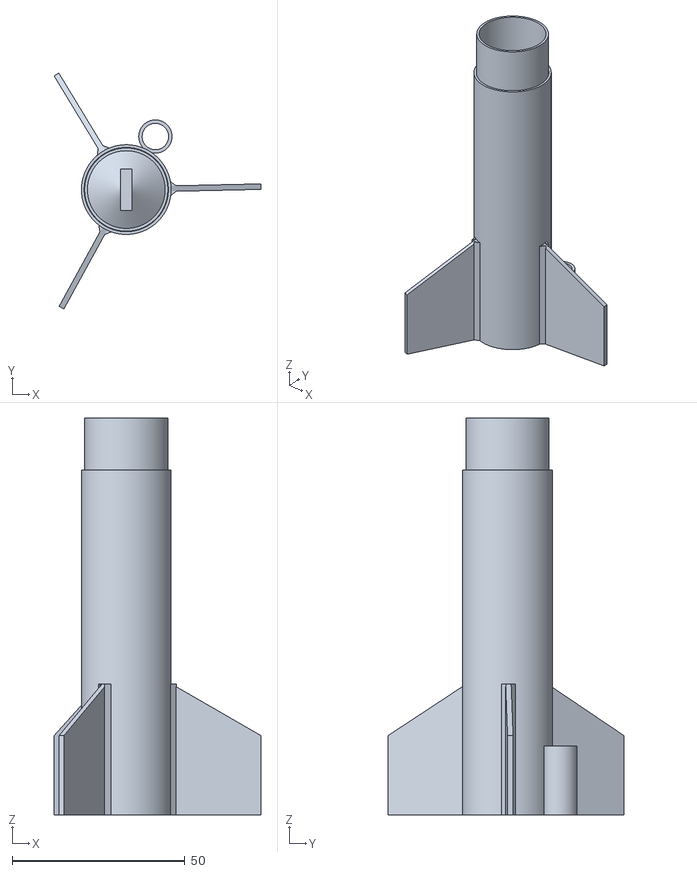
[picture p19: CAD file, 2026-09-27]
foguete2_livre/stl/F2_26mm_v1/F2_lata_aletas_v1.stl
59.9 x 68.3 x 115.0

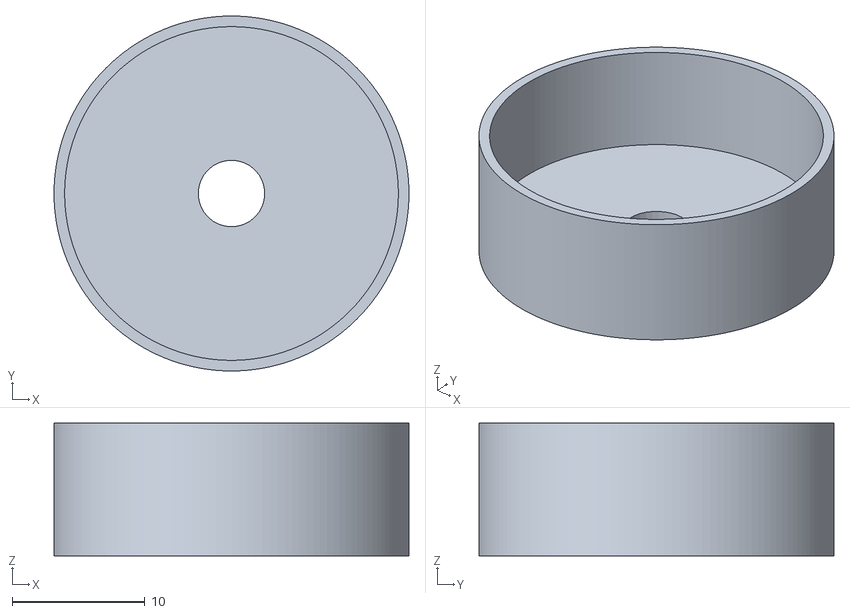
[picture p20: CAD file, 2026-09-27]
foguete2_livre/stl/F2_29mm_v1/F2_pistao_v1.stl
26.7 x 26.7 x 10.0

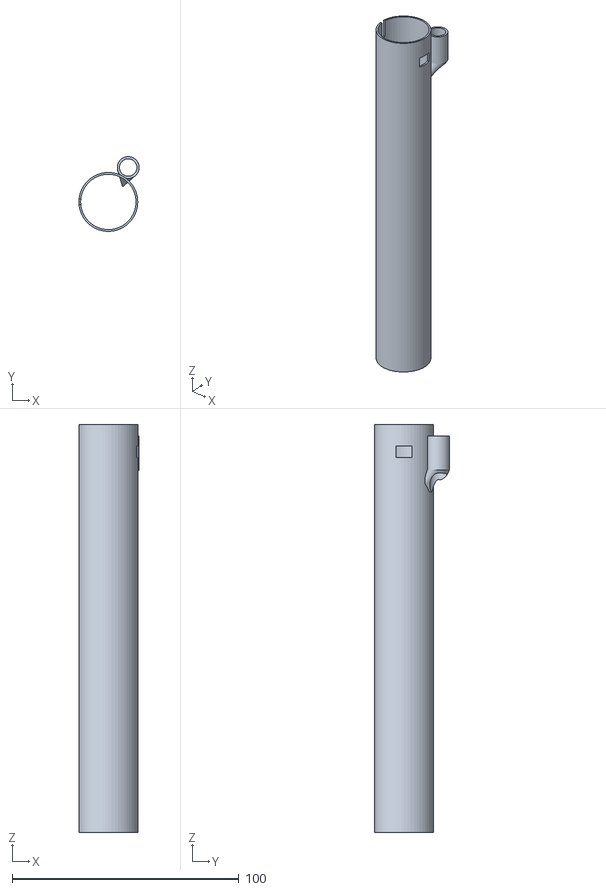
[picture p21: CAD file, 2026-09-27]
docs/modelos/F2_26_tubo.stl
26.6 x 33.0 x 180.0

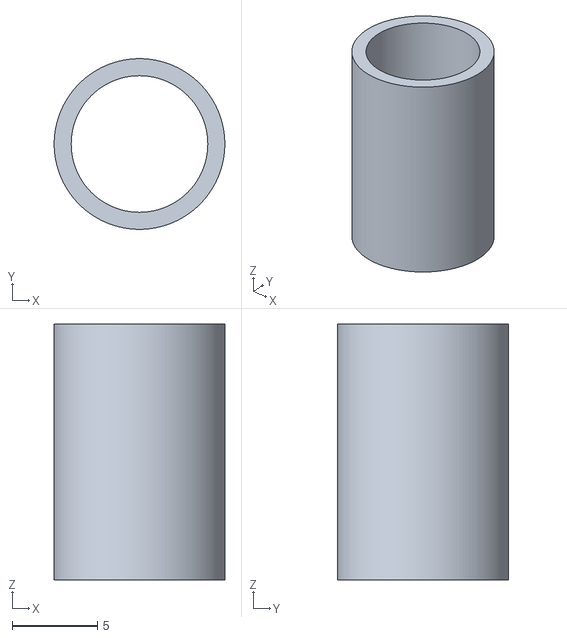
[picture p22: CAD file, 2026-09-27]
foguete1_obafog/stl/F1_construtivel_v1/gabaritos/gab_guia_haste6_ID8.0_v1.stl
10.0 x 10.0 x 15.0

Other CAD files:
foguete1_obafog/stl/F1_construtivel_v1B_ogiva_curta/gabaritos/gab_luva_motor_ID20.5_v1.stl
foguete1_obafog/stl/F1_construtivel_v1B_ogiva_curta/F1_ogiva_v1.stl
foguete1_obafog/stl/F1_construtivel_v1B_ogiva_curta/F1_lata_aletas_v1.stl
foguete1_obafog/stl/F1_construtivel_v1B_ogiva_curta/gabaritos/gab_luva_motor_ID20.3_v1.stl
docs/modelos/F1_A_lata.stl
docs/modelos/F1_A_ogiva.stl
docs/modelos/F1_B_lata.stl
docs/modelos/F1_B_tubo.stl
docs/modelos/F2_26_lata.stl
docs/modelos/F2_29_lata.stl
docs/modelos/F2_29_ogiva.stl
docs/modelos/F2_29_tubo.stl
foguete1_obafog/stl/F1_construtivel_v1/gabaritos/gab_guia_haste6_ID7.2_v1.stl
foguete1_obafog/stl/F1_construtivel_v1/gabaritos/gab_luva_motor_ID20.3_v1.stl
foguete1_obafog/stl/F1_construtivel_v1/gabaritos/gab_luva_motor_ID20.5_v1.stl
foguete1_obafog/stl/F1_construtivel_v1/gabaritos/gab_luva_motor_ID20.9_v1.stl
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

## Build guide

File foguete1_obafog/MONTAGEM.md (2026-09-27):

# Foguete 1 (OBAFOG) — montagem

As cotas e massas exatas da versão final estão em `F1_construtivel_v1_resumo.json`
(seção `cad` = massa e altura de cada STL; `params` = geometria; `estabilidade` = margem).

## 0. Antes de imprimir o foguete: gabaritos (15 minutos)

Pasta `stl/F1_construtivel_v1/gabaritos/`:

| Gabarito | Como testar | O que fazer com o resultado |
|---|---|---|
| `gab_luva_motor_ID20.3..20.9` | um cano de PVC 20 mm com **1 volta de fita crepe** tem de entrar sem forçar e sem folga | se o bom for outro que não o de 20,7 mm, ajuste `LUVA_ID` em `scripts/cad_foguetes.py` e gere de novo |
| `gab_guia_haste6_ID6.8..8.0` | deslizar na haste de 6 mm **solto**, sem prender em nenhum ponto | o foguete usa 7,65 mm; se prender, suba |

Meça também com paquímetro: **diâmetro do cano** (20,0 mm?) e **diâmetro do cap**
(tem de ser **menor que 26 mm**, o corpo). Se o cap tiver mais que 25,5 mm, avise: o corpo
precisa crescer.

## 1. Imprimir

| Peça | Orientação | Material | Fatiador |
|---|---|---|---|
| `F1_ogiva_v1.stl` | em pé, ombro na mesa | PLA ou PETG | 2 perímetros (0,8 mm), 0% preenchimento, sem topo/fundo, camada 0,15–0,2 |
| `F1_tubo_corpo_v1.stl` | em pé, guia para cima | PLA ou PETG | 2 perímetros, 0% preenchimento, sem topo/fundo |
| `F1_lata_aletas_v1.stl` | em pé, traseira na mesa | **PETG de preferência** | 3 perímetros, 30% preenchimento, brim 3 mm, camada 0,2 |

- Nenhuma peça precisa de suporte: teto da luva cônico (45°), anel dianteiro chanfrado,
  cunha de 45° embaixo da guia dianteira.
- A aleta sai **junto** com a lata: alinhamento garantido, e a flexão da aleta fica no plano
  da camada (a direção forte).
- **Altura de impressão**: confira no resumo (`altura_mm` da ogiva). Se a sua impressora não
  alcança, use a variante B (ogiva mais curta) indicada no `LEIA-ME.md`.
- Pese cada peça: diferença maior que 10% em relação ao CAD muda a margem.

## 2. Colar corpo e lata COM A HASTE (alinha as duas guias)

1. Lixe levemente o ombro da lata e o interior do tubo.
2. Enfie **as duas guias numa haste de 6 mm** (a mesma da Jornada serve) e encaixe o tubo no
   ombro da lata **com a haste passando pelas duas guias**.
3. Cole (cola instantânea ou epóxi) com a haste no lugar. As guias ficam colineares.

## 3. Lastro no bico (massa epóxi, nunca metal)

1. Pese a massa indicada no resumo (`params.ballast_g`), com passo de 0,5 g.
2. Misture a massa epóxi, role num cilindro fino, empurre até a **ponta** da ogiva com uma
   vareta de ~8 mm e soque. O modelo supõe a massa encostada na ponta (profundidade de
   enchimento no resumo, `lastro_prof_mm`).
3. Espere curar antes de encaixar a ogiva.

## 4. Pintura e identificação

- Spray **laranja ou rosa fluorescente** (achar no gramado; o edital zera foguete não achado).
  A tinta entra no modelo como ~3 g.
- Escreva escola, equipe e telefone **por dentro** da ogiva.

## 5. Conferência final (sem motor e com motor)

1. Monte tudo e pese **sem motor**: compare com `estabilidade.massa_seca_g − 14 g` do resumo
   (o resumo inclui o motor vazio).
2. Com um **motor de treino** (cano de 100 mm com cap e ~22 g de areia colada, mesma massa do
   motor carregado), ache o CG equilibrando o foguete num barbante. Compare com `cg_mm` do
   resumo: diferença de até ±5 mm é aceitável. CG mais para trás = menos margem → mais lastro.
3. Guias deslizam soltas na haste.

## 6. Motor no dia

- 1 volta de fita crepe **no tubo de PVC**, nunca no cap. O tubo entra na lata até **encostar
  no batente cônico** (é por ali que o empuxo passa).
- O cap fica 3 mm atrás da lata, **sem encostar em nada** e **sem cola, sem fita**: ele é a
  válvula de segurança do motor.
- Depois do voo, tire o motor logo (PVC quente amolece PLA).

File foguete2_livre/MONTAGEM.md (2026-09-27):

# Foguete 2 — montagem

Versões (mesmo projeto, dois diâmetros; escolha uma):

| Versão | Para quem | Arquivos |
|---|---|---|
| **F2_29mm_v1** (recomendada) | primeira eletrônica: mais espaço na baia, LiPo comum de 250 mAh, paraquedas dobra sem aperto | `F2_29mm_v1.ork`, `stl/F2_29mm_v1/` |
| F2_26mm_v1 | desempenho: ~20% mais apogeu (136 contra 114 m no motor nominal), usa a mesma lata/luva do Foguete 1, mas a baia é apertada (LiPo estreita, ~12 x 30 mm) | `F2_26mm_v1.ork`, `stl/F2_26mm_v1/` |

Números de cada versão (massa, margem, apogeu por motor, tabela de lastro, deriva):
`F2_<versão>_resumo.json`.

## 1. Imprimir

Antes de tudo, os **gabaritos** de `../foguete1_obafog/stl/<versão F1>/gabaritos/`:
anéis de luva (o cano entra com 1 volta de fita crepe sem forçar) e guias (deslizam soltas na
haste). Se o gabarito de 20,7 mm é o que serve, ajuste `LUVA_ID` em `scripts/cad_foguetes.py`
e gere de novo.

| Peça | Orientação | Material | Ajustes do fatiador |
|---|---|---|---|
| `F2_ogiva_baia_v1.stl` | em pé, ombro na mesa | PLA ou PETG | 2 perímetros (0,8 mm), 0% preenchimento, sem topo/fundo, camada 0,2 |
| `F2_tubo_corpo_v1.stl` | em pé (guia e janela para cima) | PLA ou PETG | 2 perímetros, 0% preenchimento, sem topo/fundo |
| `F2_lata_aletas_v1.stl` | em pé, traseira na mesa | **PETG de preferência** (calor do motor) | 3 perímetros, 30% preenchimento, brim de 3 mm |
| `F2_berco_eletronica_v1.stl` | em pé, antepara na mesa | PLA | 3 perímetros, 30% |
| `F2_pistao_v1.stl` | disco na mesa | PLA | 2 perímetros, 100% no disco |

Todas as peças foram modeladas para imprimir **sem suporte** (tetos cônicos, cunha de 45°
embaixo da guia dianteira). Pese cada peça: a massa do CAD está no resumo; diferença maior que
10% muda a margem — corrija no `.ork` (Componente → Sobrescrever massa).

## 2. Paraquedas

1. Imprima `moldes/molde_gomo_paraquedas_390mm.pdf` (29 mm) ou `_370mm.pdf` (26 mm) em tamanho real (confira a régua de 100 mm).
2. Corte o octógono num saco de lixo grosso (~35 µm) usando o molde 8 vezes em volta do centro.
3. Reforce os 8 cantos com um quadradinho de fita adesiva dos dois lados.
4. 8 linhas de nylon do comprimento indicado no molde; cada uma presa num canto com fita
   dobrada por cima (ou nó passando por um furo feito com agulha quente no reforço).
5. Junte as 8 pontas num nó e prenda num **destorcedor de pesca** (opcional, evita enrolar) e
   no cordão de choque, a ~1/3 do comprimento a partir da ogiva.
6. Dobre em "Z" (metade, metade, enrole as linhas em volta). Talco ajuda a não grudar.

## 3. Cordão de choque, mola e pistão

- Cordão elástico de 3 mm, **1,2 m**: uma ponta no **olhal da lata** (em cima da antepara
  cônica), passa pelo furo do pistão, outra ponta no **olhal da antepara do berço**.
- Mola de compressão por cima da antepara da lata, pistão por cima da mola, paraquedas
  dobrado por cima do pistão. A mola deve empurrar a ogiva para fora com folga quando a trava
  solta (teste do item 6). Força ~5–10 N comprimida é suficiente para uma ogiva de ~40 g.

## 4. Eletrônica no berço

Veja `eletronica/ELETRONICA.md` (ligação, orçamento de corrente, firmware).

- Servo no bolso do berço, com o braço saindo pela **fenda do ombro** da ogiva.
- ESP32-C3 nos trilhos, USB virado para trás (acesso tirando o berço).
- BMP280 **coberto com um pedaço de espuma escura** (luz e rajada atrapalham o barômetro).
- Bateria presa com fita dupla-face; **fios soldados**, sem conector solto na linha da bateria
  (conector que solta na aceleração = paraquedas que não abre).
- Chave liga/desliga acessível tirando a ogiva.

## 5. Encaixe da ogiva e trava

- A **nervura** do ombro entra no **entalhe** do topo do tubo: assim a fenda do ombro fica
  alinhada com a **janela** do tubo.
- Travado, o braço do servo entra ~2 mm na janela. Ajuste `SERVO_TRAVA_US` e `SERVO_SOLTA_US`
  no firmware até o braço entrar e sair sem esforço.
- A janela também é a tomada de ar do barômetro. Não cubra com fita.

## 6. Testes no chão (antes de qualquer voo)

1. **Ejeção**: foguete montado, paraquedas dobrado, "Destravar" pela página do Wi-Fi: a ogiva
   tem de sair e puxar o paraquedas. **10 vezes seguidas sem falhar.**
2. **Barômetro**: ruído medido na página entre 0,1 e 0,4 m.
3. **Sem disparo falso**: armado, suba e desça uma escada (5–10 m): não pode abrir.
4. **Margem estática**: pendure o foguete montado, **com motor**, num barbante e ache o
   ponto de equilíbrio (CG). Compare com o CG do `.ork` (±5 mm). O CP está no `.ork`.
5. **Bateria** acima de 3,9 V.

## 7. Onde e como lançar

- Haste de 6 mm (ou maior), 1,5 m, **87° (quase vertical), levemente contra o vento** e para
  longe das pessoas.
- **Altura**: com o motor nominal (7 N·s) o apogeu fica abaixo de 150 m. Com motor mais forte
  passa disso. A norma BAR-2/2020 pede NOTAM acima de 150 m em área rural. Depois do teste
  estático, veja a **tabela de lastro** no resumo: ela diz quantos gramas de massa epóxi pôr no
  bico para ficar abaixo de 140 m, ou avisa quando nem o lastro máximo resolve.
- **Campo**: a deriva com vento de 4 m/s passa de 50 m (tabela de deriva no resumo). Campo de
  futebol vazio, sem fios e sem árvores altas.
- Público a pelo menos metade do apogeu esperado (protocolo da OBA, vídeo 215); todos com
  proteção nos olhos; adulto responsável junto.

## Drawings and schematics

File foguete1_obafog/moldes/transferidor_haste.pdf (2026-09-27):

# Transferidor da haste — lê a ELEVAÇÃO direto

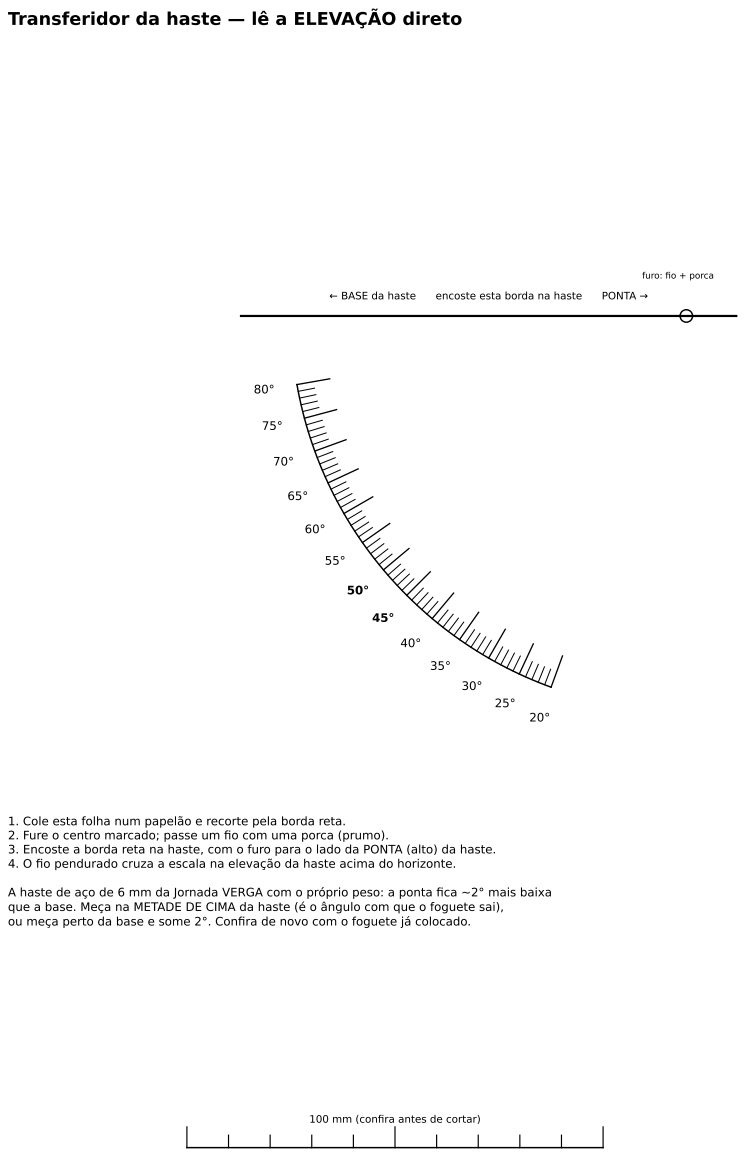
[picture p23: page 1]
← BASE da haste; encoste esta borda na haste; PONTA →

furo: fio + porca

1. Cole esta folha num papelão e recorte pela borda reta.
2. Fure o centro marcado; passe um fio com uma porca (prumo).
3. Encoste a borda reta na haste, com o furo para o lado da PONTA (alto) da haste.
4. O fio pendurado cruza a escala na elevação da haste acima do horizonte.

A haste de aço de 6 mm da Jornada VERGA com o próprio peso: a ponta fica ~2° mais baixa
que a base. Meça na METADE DE CIMA da haste (é o ângulo com que o foguete sai),
ou meça perto da base e some 2°. Confira de novo com o foguete já colocado.

100 mm (confira antes de cortar)

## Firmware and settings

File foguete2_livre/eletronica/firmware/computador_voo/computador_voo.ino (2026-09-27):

/*
  Computador de voo — Foguete 2 (livre)  |  ESP32-C3 SuperMini, core esp32 3.x
  Barômetro BMP280 (obrigatório) + MPU6050 (opcional) + micro servo (trava da ogiva)
  + buzzer (localizador) + LiPo 1S. A lógica de voo está em voo.h (testada no PC).

  PLACA na IDE: "ESP32C3 Dev Module", USB CDC On Boot: Enabled.
  Compilar: arduino-cli compile --fqbn esp32:esp32:esp32c3:CDCOnBoot=cdc computador_voo

  LIGAÇÃO (ver ../../ELETRONICA.md)
    GPIO6 SDA, GPIO7 SCL  -> BMP280 e MPU6050 (3V3, GND)
    GPIO5 -> sinal do servo (servo alimentado DIRETO na bateria, depois da chave)
    GPIO4 -> resistor 1k -> base do NPN (S8050/BC337); buzzer ativo entre bateria+ e coletor
    GPIO3 <- meio de um divisor 100k/100k da bateria (leitura de tensão)
    GPIO8 = LED azul da placa (acende em LOW)
    Bateria + (depois da chave) -> pino 5V da placa (regulador da placa faz 3,3 V)
  NUNCA ligar o USB com a chave da bateria ligada (o USB empurra 5 V na LiPo),
  a menos que exista um diodo Schottky (SS14/1N5817) entre bateria e pino 5V.

  OPERAÇÃO
    1. Liga (ogiva fora): servo DESTRAVADO, Wi-Fi "FOGUETE2" (senha foguete123), 1 bip a cada 2 s.
    2. Encaixa a ogiva. No celular, http://192.168.4.1 -> "Travar e armar"
       (ou espere 90 s: nos últimos 10 s ele bipa rápido e trava sozinho).
    3. ARMADO: servo travado, Wi-Fi desligado, bip duplo a cada 5 s = tudo certo.
       Bips rápidos contínuos = sensor com problema -> NÃO lançar.
    4. Depois do pouso: bipa o apogeu (ex.: 1-2-3 = 123 m), Wi-Fi volta, baixa /voo.csv.
*/
#include <LittleFS.h>
#include <WebServer.h>
#include <WiFi.h>
#include <Wire.h>
#include <esp_system.h>

#include "bmp280_min.h"
#include "voo.h"

// ---------------- pinos e ajustes ----------------
const int PIN_SDA = 6, PIN_SCL = 7, PIN_SERVO = 5, PIN_BUZZER = 4, PIN_BAT = 3, PIN_LED = 8;
const int SERVO_TRAVA_US = 1900;     // AJUSTAR na bancada: braço dentro da janela do tubo
const int SERVO_SOLTA_US = 1100;     // AJUSTAR: braço recolhido, ogiva livre
const uint32_t AUTO_ARMAR_MS = 90000;
const uint32_t PERIODO_MS = 20;      // 50 Hz
const char* WIFI_SSID = "FOGUETE2";
const char* WIFI_SENHA = "foguete123";

// ---------------- estado ----------------
BMP280min baro;
bool temMPU = false, baroOK = false;
voo::Computador fc;
WebServer web(80);
bool wifiLigado = false;
uint32_t tLigou = 0, tUltimaAmostra = 0, tServoMov = 0;
float pressao = 101325, temperatura = 25, vBat = 0;
int16_t az_mg = 0;

// sobrevive a reset por queda de tensão (não a desligar a bateria)
RTC_NOINIT_ATTR uint32_t rtcMagic;
RTC_NOINIT_ATTR uint8_t rtcEstado;
const uint32_t MAGIC = 0xF0E6E7E2;

// ---------------- log do voo em RAM (salvo na flash depois do pouso) ----------------
struct Amostra {
  uint32_t t;
  float h_bruto, h, v;
  int16_t az;
  uint8_t estado, flags;
};
const int N_LOG = 3000;              // 60 s a 50 Hz (~60 kB)
Amostra logv[N_LOG];
int iLog = 0, iInicio = -1, nLog = 0;
bool gravando = false, salvo = false;

// ---------------- servo por LEDC (sem biblioteca) ----------------
void servoPulso(int us) {
  // 50 Hz, 14 bits: período 20000 us = 16384 contagens
  ledcWrite(PIN_SERVO, (uint32_t)us * 16384UL / 20000UL);
  tServoMov = millis();
}
void servoDesliga() { ledcWrite(PIN_SERVO, 0); }

// ---------------- buzzer não bloqueante ----------------
void buzz(bool on) { digitalWrite(PIN_BUZZER, on ? HIGH : LOW); }
void padraoBip(uint32_t agora) {
  using E = voo::Estado;
  bool ligado = false;
  if (!baroOK) {                                   // erro: 5 Hz
    ligado = (agora / 100) % 2;
  } else if (fc.estado == E::PREPARO) {
    uint32_t restante = (agora - tLigou < AUTO_ARMAR_MS) ? AUTO_ARMAR_MS - (agora - tLigou) : 0;
    ligado = (restante < 10000) ? ((agora / 150) % 2) : ((agora % 2000) < 60);
  } else if (fc.estado == E::ARMADO) {
    uint32_t c = agora % 5000;
    ligado = c < 60 || (c > 180 && c < 240);
  } else if (fc.estado == E::POUSADO) {
    // bipa os dígitos do apogeu, depois 5 s de bip curto por segundo, repete
    int ap = (int)(fc.h_max + 0.5f);
    int d[3] = {ap / 100, (ap / 10) % 10, ap % 10};
    uint32_t ciclo = 16000, c = agora % ciclo;
    uint32_t pos = 0;
    ligado = false;
    for (int k = (ap >= 100 ? 0 : (ap >= 10 ? 1 : 2)); k < 3 && !ligado; k++) {
      int n = d[k] == 0 ? 1 : d[k];
      uint32_t dur = d[k] == 0 ? 600 : 150;
      for (int j = 0; j < n; j++) {
        if (c >= pos && c < pos + dur) { ligado = true; break; }
        pos += dur + 250;
      }
      pos += 700;
    }
    if (!ligado && c > 9000) ligado = (c % 1000) < 50;
  }
  buzz(ligado);
  digitalWrite(PIN_LED, ligado ? LOW : HIGH);
}

// ---------------- sensores ----------------
bool mpuInit() {
  Wire.beginTransmission(0x68);
  if (Wire.endTransmission() != 0) return false;
  auto w = [](uint8_t r, uint8_t v) { Wire.beginTransmission(0x68); Wire.write(r); Wire.write(v); Wire.endTransmission(); };
  w(0x6B, 0x00);        // acorda
  w(0x1C, 0x18);        // acelerômetro +-16 g (2048 LSB/g)
  w(0x1A, 0x03);        // filtro digital ~44 Hz
  return true;
}
bool mpuLerAz(int16_t& mg) {
  Wire.beginTransmission(0x68);
  Wire.write(0x3B);
  if (Wire.endTransmission(false) != 0) return false;
  if (Wire.requestFrom(0x68, 6) != 6) return false;
  int16_t ax = (Wire.read() << 8) | Wire.read();
  int16_t ay = (Wire.read() << 8) | Wire.read();
  int16_t azr = (Wire.read() << 8) | Wire.read();
  // módulo da aceleração (orientação do módulo no berço não importa para detectar decolagem)
  float g = sqrtf((float)ax * ax + (float)ay * ay + (float)azr * azr) / 2048.0f;
  mg = (int16_t)constrain(g * 1000.0f, -32000.0f, 32000.0f);
  return true;
}

float lerBateria() { return analogReadMilliVolts(PIN_BAT) * 2.0f / 1000.0f; }

// ---------------- log ----------------
void registrar(uint32_t t, uint8_t flags) {
  if (iInicio >= 0 && !gravando) return;           // voo já gravado ou buffer cheio: não sobrescreve
  Amostra& a = logv[iLog];
  a.t = t; a.h_bruto = fc.h_bruto; a.h = fc.kf.h; a.v = fc.kf.v; a.az = az_mg;
  a.estado = (uint8_t)fc.estado; a.flags = flags;
  iLog = (iLog + 1) % N_LOG;
  if (gravando && ++nLog >= N_LOG - 1) gravando = false;   // cheio: congela
}

void salvarVoo() {
  if (salvo || iInicio < 0) return;
  File f = LittleFS.open("/voo.csv", "w");
  if (!f) return;
  f.printf("# apogeu_m=%.1f motivo=%s t_decolagem=%lu t_abertura=%lu bateria=%.2f\n",
           fc.h_max, fc.motivo, (unsigned long)fc.t_decolagem, (unsigned long)fc.t_abertura, vBat);
  f.println("t_ms,h_bruto_m,h_filtrado_m,v_ms,acel_mg,estado,flags");
  int n = min(nLog, N_LOG - 1);
  for (int k = 0; k < n; k++) {
    const Amostra& a = logv[(iInicio + k) % N_LOG];
    f.printf("%lu,%.2f,%.2f,%.2f,%d,%u,%u\n", (unsigned long)a.t, a.h_bruto, a.h, a.v, a.az, a.estado, a.flags);
  }
  f.close();
  salvo = true;
}

// ---------------- Wi-Fi (só no chão) ----------------
void paginaStatus() {
  String s = "<html><head><meta name=viewport content='width=device-width'><meta http-equiv=refresh content=2>"
             "<style>body{font-family:sans-serif;font-size:18px}a{display:block;margin:12px 0;padding:14px;"
             "background:#e8590c;color:#fff;text-align:center;border-radius:8px;text-decoration:none}</style>"
             "</head><body><h2>Foguete 2</h2>";
  s += "Estado: <b>" + String(voo::nome(fc.estado)) + "</b><br>";
  s += "Barometro: " + String(baroOK ? "OK" : "FALHA") + " | MPU6050: " + String(temMPU ? "sim" : "nao") + "<br>";
  s += "Bateria: " + String(vBat, 2) + " V" + String(vBat < 3.6 ? " (CARREGAR)" : "") + "<br>";
  s += "Altitude relativa: " + String(fc.kf.h, 1) + " m | ruido medido: " + String(fc.cfg.sigma_h_m, 2) + " m<br>";
  s += "Apogeu registrado: " + String(fc.h_max, 1) + " m (" + String(fc.motivo) + ")<br>";
  if (fc.estado == voo::Estado::PREPARO) {
    uint32_t r = AUTO_ARMAR_MS - min(AUTO_ARMAR_MS, millis() - tLigou);
    s += "Arma sozinho em " + String(r / 1000) + " s<br>";
    s += "<a href=/armar>Travar e armar</a><a href=/destravar>Destravar (teste)</a><a href=/travar>Travar (teste)</a>";
  }
  s += "<a href=/voo.csv>Baixar voo.csv</a></body></html>";
  web.send(200, "text/html", s);
}

void wifiLiga() {
  if (wifiLigado) return;
  WiFi.mode(WIFI_AP);
  WiFi.softAP(WIFI_SSID, WIFI_SENHA);
  static bool rotas = false;
  if (rotas) { web.begin(); wifiLigado = true; return; }
  rotas = true;
  web.on("/", paginaStatus);
  web.on("/armar", []() { armar(); web.sendHeader("Location", "/"); web.send(303); });
  web.on("/destravar", []() {
    if (fc.estado == voo::Estado::PREPARO || fc.estado == voo::Estado::POUSADO) servoPulso(SERVO_SOLTA_US);
    web.sendHeader("Location", "/"); web.send(303);
  });
  web.on("/travar", []() {
    if (fc.estado == voo::Estado::PREPARO) servoPulso(SERVO_TRAVA_US);
    web.sendHeader("Location", "/"); web.send(303);
  });
  web.on("/voo.csv", []() {
    File f = LittleFS.open("/voo.csv", "r");
    if (!f) { web.send(404, "text/plain", "sem voo gravado"); return; }
    web.streamFile(f, "text/csv");
    f.close();
  });
  web.begin();
  wifiLigado = true;
}

void wifiDesliga() {
  if (!wifiLigado) return;
  web.stop();
  WiFi.softAPdisconnect(true);
  WiFi.mode(WIFI_OFF);
  wifiLigado = false;
}

// ---------------- armar ----------------
float mediaPressao(int n) {
  float soma = 0; int ok = 0;
  for (int i = 0; i < n * 3 && ok < n; i++) {
    float p, t;
    if (baro.ler(p, t)) { soma += p; ok++; }
    delay(15);
  }
  return ok ? soma / ok : pressao;
}

void medirRuido() {
  // desvio da altitude bruta parado no chão -> ruído do Kalman
  const int n = 60;
  float h[n], p0 = mediaPressao(10), m = 0, v = 0;
  for (int i = 0; i < n; i++) {
    float p = p0, t;
    for (int k = 0; k < 20 && !baro.ler(p, t); k++) delay(2);   // limitado: nunca trava
    h[i] = voo::altitude_de_pressao(p, p0);
    m += h[i];
    delay(20);
  }
  m /= n;
  for (int i = 0; i < n; i++) v += (h[i] - m) * (h[i] - m);
  fc.cfg.sigma_h_m = constrain(sqrtf(v / (n - 1)), 0.1f, 1.5f);
}

void armar() {
  if (fc.estado != voo::Estado::PREPARO || !baroOK) return;
  servoPulso(SERVO_TRAVA_US);
  medirRuido();
  fc.armar(mediaPressao(20), millis());
  rtcMagic = MAGIC;
  rtcEstado = (uint8_t)fc.estado;
  wifiDesliga();
  iInicio = -1; nLog = 0; gravando = false; salvo = false;
}

// ---------------- setup / loop ----------------
void setup() {
  pinMode(PIN_BUZZER, OUTPUT); buzz(false);
  pinMode(PIN_LED, OUTPUT); digitalWrite(PIN_LED, HIGH);
  Serial.begin(115200);
  analogSetPinAttenuation(PIN_BAT, ADC_11db);
  ledcAttach(PIN_SERVO, 50, 14);
  Wire.begin(PIN_SDA, PIN_SCL, 400000);
  baroOK = baro.begin(Wire);
  temMPU = mpuInit();
  LittleFS.begin(true);
  tLigou = millis();
  vBat = lerBateria();

  // reset DURANTE o voo (queda de tensão)? então abre o paraquedas já: melhor que nunca abrir
  esp_reset_reason_t motivo = esp_reset_reason();
  bool resetEmVoo = (rtcMagic == MAGIC) &&
                    (rtcEstado == (uint8_t)voo::Estado::SUBIDA || rtcEstado == (uint8_t)voo::Estado::DESCIDA) &&
                    (motivo == ESP_RST_BROWNOUT || motivo == ESP_RST_PANIC || motivo == ESP_RST_WDT ||
                     motivo == ESP_RST_INT_WDT || motivo == ESP_RST_TASK_WDT);
  if (resetEmVoo) {
    servoPulso(SERVO_SOLTA_US);
    fc.estado = voo::Estado::DESCIDA;
    fc.motivo = "reset em voo";
    Serial.println("# reset em voo: paraquedas comandado");
  } else {
    servoPulso(SERVO_SOLTA_US);      // ogiva livre para encaixar
    wifiLiga();
  }
  rtcMagic = MAGIC;
  rtcEstado = (uint8_t)fc.estado;
  Serial.printf("# baro %s (0x%02X, id 0x%02X) | MPU %s | bateria %.2f V\n", baroOK ? "OK" : "FALHA",
                baro.endereco, baro.chip_id, temMPU ? "sim" : "nao", vBat);
}

void loop() {
  uint32_t agora = millis();
  if (wifiLigado) web.handleClient();

  // servo segura a posição o tempo todo (trava com torque); só desliga 5 s depois do pouso
  if (tServoMov && agora - tServoMov > 5000 && fc.estado == voo::Estado::POUSADO) {
    servoDesliga();
    tServoMov = 0;
  }

  // sensor com falha não trava a placa: tenta de novo a cada 500 ms (diagnóstico não bloqueia)
  static uint32_t tRetry = 0;
  if (!baroOK && agora - tRetry > 500) { tRetry = agora; baroOK = baro.begin(Wire); }

  if (fc.estado == voo::Estado::PREPARO && agora - tLigou > AUTO_ARMAR_MS) armar();

  if (agora - tUltimaAmostra >= PERIODO_MS) {
    tUltimaAmostra = agora;
    float p, t;
    bool ok = baroOK && baro.ler(p, t);
    if (ok) { pressao = p; temperatura = t; }
    if (temMPU && mpuLerAz(az_mg) && az_mg > 3000 && fc.estado == voo::Estado::ARMADO) fc.sinal_decolagem();
    voo::Estado antes = fc.estado;
    voo::Saida s = fc.passo(agora, pressao);
    if (s.abrir) servoPulso(SERVO_SOLTA_US);
    if (antes == voo::Estado::ARMADO && fc.estado == voo::Estado::SUBIDA) {
      gravando = true;
      nLog = 50;                                       // guarda 1 s antes da decolagem
      iInicio = (iLog - 50 + N_LOG) % N_LOG;
    }
    if (fc.estado != voo::Estado::PREPARO) registrar(agora, (ok ? 1 : 0) | (s.abrir ? 2 : 0));
    if (s.mudou_estado) {
      rtcEstado = (uint8_t)fc.estado;
      Serial.printf("# %lu ms: %s (h=%.1f v=%.1f %s)\n", (unsigned long)agora, voo::nome(fc.estado),
                    fc.kf.h, fc.kf.v, fc.motivo);
    }
    if (fc.estado == voo::Estado::POUSADO && !salvo) {
      gravando = false;
      salvarVoo();
      vBat = lerBateria();
      wifiLiga();
    }
    static uint32_t tBat = 0;
    if (agora - tBat > 5000 && fc.estado != voo::Estado::SUBIDA) { tBat = agora; vBat = lerBateria(); }
  }
  padraoBip(agora);
}

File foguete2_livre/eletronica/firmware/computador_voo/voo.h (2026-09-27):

// voo.h — lógica de voo PORTÁTIL (sem Arduino): filtro de Kalman + máquina de estados.
//
// O mesmo arquivo compila no ESP32-C3 (computador_voo.ino) e no PC (../../sil/teste_voo.cpp),
// onde é testado com as trajetórias simuladas no OpenRocket + ruído de barômetro.
//
// Entrada: pressão (Pa) com carimbo de tempo (ms).  Saída: "abrir" (solta a ogiva/paraquedas).
//
// Estados:
//   PREPARO  -> ligado no chão, servo destravado, espera o operador (ou o tempo) armar
//   ARMADO   -> servo travado, pressão do chão sendo acompanhada, espera decolagem
//   SUBIDA   -> decolou; depois do bloqueio procura o apogeu (ou vence o tempo de backup)
//   DESCIDA  -> paraquedas comandado; espera pousar
//   POUSADO  -> parado no chão: salva o voo, liga o Wi-Fi, bipa o apogeu
#pragma once
#include <math.h>
#include <stdint.h>

namespace voo {

enum class Estado : uint8_t { PREPARO = 0, ARMADO = 1, SUBIDA = 2, DESCIDA = 3, POUSADO = 4 };

inline const char* nome(Estado e) {
  switch (e) {
    case Estado::PREPARO: return "PREPARO";
    case Estado::ARMADO: return "ARMADO";
    case Estado::SUBIDA: return "SUBIDA";
    case Estado::DESCIDA: return "DESCIDA";
    case Estado::POUSADO: return "POUSADO";
  }
  return "?";
}

struct Config {
  // tempos contados a partir da DETECÇÃO da decolagem (que chega ~0,4 s depois do real)
  float bloqueio_s     = 1.6f;   // nunca abre antes (queima de ~1,2 s + margem)
  float backup_s       = 8.5f;   // abre por tempo se o apogeu não foi detectado (apogeu de 11,5 N.s ~7,8 s)
  float h_decolagem_m  = 4.0f;   // decolagem = altitude filtrada acima disto...
  float v_decolagem_ms = 6.0f;   // ...e subindo mais rápido que isto
  float v_apogeu_ms    = -0.3f;  // apogeu = velocidade filtrada abaixo disto...
  int   n_apogeu       = 4;      // ...por N amostras seguidas (80 ms a 50 Hz)
  float queda_apogeu_m = 2.5f;   // ...ou altitude caiu isto abaixo do máximo
  float h_min_abrir_m  = 12.0f;  // não abre por apogeu abaixo disto (backup abre em qualquer altura)
  float v_pouso_ms     = 0.8f;   // pouso = |v suavizada| menor que isto...
  float t_pouso_s      = 3.0f;   // ...durante este tempo
  float t_descida_max_s = 120.0f; // ...ou, por garantia, este tempo depois da abertura
  float porta_sigma    = 6.0f;   // rejeita medida com resíduo > 6 sigma (picos do sensor)
  float sigma_h_m      = 0.35f;  // ruído do barômetro (m); o .ino mede no chão e corrige
  float sigma_a_prop   = 60.0f;  // m/s2: incerteza da aceleração durante a propulsão
  float sigma_a_voo    = 10.0f;  // m/s2: depois da queima
  float tau_chao_s     = 60.0f;  // pressão do chão acompanhada devagar enquanto ARMADO
};

inline float altitude_de_pressao(float p, float p0) {
  return 44330.0f * (1.0f - powf(p / p0, 0.190295f));   // atmosfera padrão (relativa ao chão)
}

// Kalman de 2 estados [h, v] com aceleração desconhecida tratada como ruído branco
struct Kalman2 {
  float h = 0, v = 0, P00 = 1, P01 = 0, P10 = 0, P11 = 1;
  int rejeitadas = 0;
  void reset(float h0) { h = h0; v = 0; P00 = 1; P01 = P10 = 0; P11 = 1; rejeitadas = 0; }
  // porta > 0: ignora a medida se o resíduo passar de porta*sigma (pico de sensor)
  void passo(float dt, float z, float sigma_a, float sigma_z, float porta = 0) {
    h += v * dt;
    const float q = sigma_a * sigma_a, dt2 = dt * dt, dt3 = dt2 * dt, dt4 = dt3 * dt;
    const float n00 = P00 + dt * (P10 + P01) + dt2 * P11 + q * dt4 * 0.25f;
    const float n01 = P01 + dt * P11 + q * dt3 * 0.5f;
    const float n10 = P10 + dt * P11 + q * dt3 * 0.5f;
    const float n11 = P11 + q * dt2;
    const float S = n00 + sigma_z * sigma_z;
    const float K0 = n00 / S, K1 = n10 / S;
    const float r = z - h;
    if (porta > 0 && r * r > porta * porta * S && rejeitadas < 5) {
      // só predição: aceita no máximo 5 seguidas (se for real, o filtro volta a seguir)
      P00 = n00; P01 = n01; P10 = n10; P11 = n11;
      rejeitadas++;
      return;
    }
    rejeitadas = 0;
    h += K0 * r;
    v += K1 * r;
    P00 = (1 - K0) * n00; P01 = (1 - K0) * n01;
    P10 = n10 - K1 * n00; P11 = n11 - K1 * n01;
  }
};

struct Saida {
  bool abrir = false;         // true UMA vez: soltar a ogiva agora
  bool mudou_estado = false;
};

class Computador {
 public:
  Config cfg;
  Estado estado = Estado::PREPARO;
  Kalman2 kf;
  float p0 = 101325.0f;       // pressão do chão
  float h_bruto = 0;          // altitude sem filtro (log)
  float h_max = 0;            // apogeu registrado (filtrado)
  uint32_t t_decolagem = 0, t_abertura = 0;
  const char* motivo = "";    // "velocidade", "queda", "tempo"
  bool decolagem_externa = false;   // acelerômetro (opcional) viu a decolagem
  float v_suave = 0;                // velocidade passada num filtro de ~1 s

  void armar(float p_chao, uint32_t t_ms) {
    p0 = p_chao;
    kf.reset(0);
    h_max = 0;
    cont_ = 0;
    t_ant_ = t_ms;
    parado_desde_ = 0;
    decolagem_externa = false;
    v_suave = 0;
    motivo = "";
    estado = Estado::ARMADO;
  }

  // o .ino chama quando o acelerômetro passa de ~3 g (opcional; sem ele, só barômetro)
  void sinal_decolagem() { decolagem_externa = true; }
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

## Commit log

2026-09-27 Publica o projeto dos dois foguetes com o motor sólido da OBAFOG
    Foguete 1 (OBAFOG Modelo 5, alcance) e Foguete 2 (livre, com computador
    de voo e paraquedas), com pesquisa, modelo do motor, arquivos do
    OpenRocket, STL para impressão, firmware testado em simulação e a página
    do projeto em docs/ (GitHub Pages).
    Claude-Session: https://claude.ai/code/session_01ProobUySXTcPtGZErauuk8
    [F1_A_lata.stl, F1_A_ogiva.stl, F1_B_lata.stl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]
2026-09-27 Documenta os scripts da página e usa as massas do STL de impressão no 3D
    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
